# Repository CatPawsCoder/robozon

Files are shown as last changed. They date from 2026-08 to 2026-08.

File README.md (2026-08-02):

# Задача 3. Интеллектуальная роботизированная система сортировки товаров

Программно-аппаратный комплекс (ПАК) предварительной сортировки товаров
на участке сортировочного центра: определение категории товара по
формальным правилам постановки и физическая маршрутизация в зону
обработки B / C / D.

**Концепция:** геометрический сортировочный ПАК — детерминированная
классификация по правилам постановки (габариты → «круг в сечении» →
приоритет), цифровой двойник участка, исполнительный узел
«накопитель-лоток» (tilt-tray) с тремя приводами, синхронизация с
конвейером 1 м/с, CSV-метрики и видео полного цикла.

---

## Структура решения

```
robozone-task3/
├── classifier/                # ЧАСТЬ ОПРЕДЕЛЕНИЯ И КЛАССИФИКАЦИИ
│   ├── geometry.py            #   OBB-габариты; r_in/R_out по сечениям;
│   │                          #   анализ облака точек, эллипс-фит
│   ├── rules.py               #   правила B/C/D (приоритет: габариты → форма)
│   └── run_classification.py  #   CLI: STL → CSV + PNG решающих сечений
├── perception/                # RGB-D КОНТУР ВОСПРИЯТИЯ (пиксели → категория)
│   └── rgbd_pipeline.py       #   3 depth-камеры → облако → габариты/круг → B/C/D
├── sim/                       # ИСПОЛНИТЕЛЬНАЯ ЧАСТЬ (цифровой двойник)
│   └── conveyor_sim.py        #   MuJoCo: конвейер → tilt-tray → зоны B/C/D
├── hardware/                  # ФИЗИЧЕСКИЙ УЗЕЛ (проект + прошивка)
│   ├── tray_controller/       #   прошивка ESP8266 для 3-позиционного лотка
│   └── send_category.py       #   мост «классификатор → лоток» по HTTP
├── docs/
│   ├── REPORT.md              #   итоговый отчёт
│   ├── PHYSICAL_UNIT.md       #   проект физ. узла: кинематика, BOM, расчёты
│   └── presentation.pptx      #   презентация решения
├── tests/                     # 35 юнит-тестов (правила, геометрия, восприятие)
├── data/
│   ├── models/                # исходный тестовый набор STL (11 объектов)
│   └── models_sim/            # выпуклые оболочки для коллизий симуляции
├── output/                    # результаты (генерируются при запуске)
│   ├── classification.csv     #   таблица классификации
│   ├── sections/*.png         #   визуализация решающих сечений
│   ├── perception/*.csv,*.png #   RGB-D: измерения, облака точек, depth-кадры
│   ├── sim_log.csv            #   маршрутизация и cycle time по товарам
│   ├── sim_events.csv         #   нештатные события (jam, estop, boost...)
│   └── sim_demo.mp4           #   видеодемонстрация (запуск с --video)
├── requirements.txt
└── README.md
```

## Быстрый старт

```bash
pip install -r requirements.txt

# 1. Классификация тестового набора (STL -> категории B/C/D)
python -m classifier.run_classification --models data/models --out output

# 2. RGB-D контур: система «видит» товар depth-камерами -> категория (11/11)
python -m perception.rgbd_pipeline
python -m perception.rgbd_pipeline --poses   # устойчивость к ориентации

# 3. Симуляция полного цикла (headless, лог в output/sim_log.csv)
python -m sim.conveyor_sim
python -m sim.conveyor_sim --video           # + видео
python -m sim.conveyor_sim --stress          # стресс-прогон вариаций подачи

# 4. Тесты
pytest tests/ -v
```

Проверено: Python 3.10, Windows 11. Все зависимости — open-source
из перечня допустимого ПО (MuJoCo, trimesh, shapely, SciPy, NumPy).

---

## 1. Часть определения и классификации товара

Классификация **детерминированная, по формальным правилам постановки**
(не семантическая «бутылка/коробка», а геометрия):

1. **Габариты** (приоритетная проверка): товар должен помещаться в
   допуск основного сортировщика 10×10×10 … 450×320×320 мм.
   Сравнение — поэлементно после сортировки габаритов по убыванию
   (эквивалент «влезает в проём в какой-либо ориентации»).
   Не проходит → **категория C**.
2. **«Круг в сечении»**: если существует сечение, у которого отношение
   радиуса вписанной окружности к радиусу описанной ≥ 0,8 → **категория D**.
3. Иначе → **категория B** (подходит для сортировки).

Реализация метрики круга (см. `classifier/geometry.py`):
- меш выравнивается по осям минимального ориентированного bounding box;
- сечения берутся перпендикулярно трём осям OBB (15 позиций на ось);
- контур сечения = выпуклая оболочка (осознанно: круглое **катится**
  по внешней огибающей; устойчиво к не-watertight STL);
- r_in — pole of inaccessibility (shapely polylabel),
  R_out — минимальная охватывающая окружность (алгоритм Вельцля,
  фиксированный seed → воспроизводимо).

### Результат на тестовом наборе (output/classification.csv)

| Объект | Габариты, мм (↓) | r/R | Категория | Комментарий |
|---|---|---:|:-:|---|
| Бутылка | 305×91×91 | 1.00 | **D** | круг поперёк корпуса |
| ЛанчБокс | 201×152×62 | 0.66 | **B** | |
| Цилиндр | 435×50×43 | 0.87 | **D** | эллипс 43/50 = 0.86 — над порогом |
| Мешок | 202×176×170 | 0.89 | **D** | неочевидный D |
| Ручка | 148×13×9 | 1.00 | **C** | 9 мм < минимума 10 мм |
| Короб 300×200×200 | 301×200×200 | 0.72 | **B** | |
| Пуфик | 489×489×264 | 1.00 | **C** | 489 > 320: габарит бьёт форму |
| Короб 400×400×300 | 401×400×300 | 0.72 | **C** | 400 > 320 — ловушка |
| Тарелка | 210×209×27 | 1.00 | **D** | |
| Шлем | 352×298×282 | 0.90 | **D** | неочевидный D |
| Моющее средство | 280×260×179 | 0.73 | **B** | |

Каждое решение сопровождается PNG решающего сечения
(`output/sections/`): контур + вписанная и описанная окружности +
коэффициент — решение проверяемо, а не декларируется.

Пограничные случаи: коэффициент в зоне 0,8 ± 0,05 помечается
`manual_review_required` — категория назначается по формальному правилу
(отдельной зоны вне B/C/D не вводится), событие логируется для оператора.

### RGB-D контур: система «видит» товар (perception/)

Тот же классификатор работает и по данным виртуальных depth-камер —
замкнут контур **пиксели → категория**:

```
3 depth-камеры (верх + 2 бока 45°) → облако точек → сегментация от ленты
   → фильтр «летающих пикселей» + SOR → габариты + метрика круга
   (аппроксимация эллипса по видимой дуге) → правила B/C/D → команда
```

**Алгоритмика классификации не меняется** — те же правила и метрика, что
для STL; меняется лишь источник геометрии (облако точек вместо меша).
Результат: **11/11 категорий совпадают с эталоном**
(`output/perception/perception_results.csv`), устойчивость к ориентации —
**55/55 измерений** на 5 углах поворота (`--poses`). Каждое измерение
сопровождается depth-кадром и облаком точек (`output/perception/*.png`).

## 2. Исполнительная часть

**Механизм: накопитель-лоток (tilt-tray) на трёх приводах** —
промышленная схема tilt-tray сортеров:

1. **Приём** — лоток с V-образным ложем стоит горизонтально под срезом
   подающего конвейера; товар сходит с ленты через мостик-переходник,
   гасит скорость о встречный склон и оседает в ложбине. Катящийся
   товар (бутылка, тарелка, пуфик) ловит торцевой флап.
2. **Поворот** — сервопривод yaw доворачивает лоток на угол зоны:
   B = 0°, C = +55°, D = −55°. Товар неподвижен в момент поворота —
   исключён перелёт через борт (боковой момент = 0).
3. **Опрокидывание** — сервопривод tilt наклоняет ложе на 34,5°,
   торцевой флап открывается как продолжение склона; товар сходит
   в зону по направляющим юбкам (в кейджи C/D — по каналу юбок).

Ключевые конструктивные решения (все проверены симуляцией):
- **мостик-переходник** закрывает щель лента/лоток — тонкий товар
  (ручка 9 мм) не проваливается; лоток вращается под мостиком;
- **тормозной фартук** на последних 0,4 м ленты гасит вход до ~0,45 м/с;
- **V-ложе + флап** останавливают и качение, и скольжение при приёме;
- **высокие борта** разгонного участка — высокий круглый товар (шлем)
  не скатывается с ленты;
- клиренсы поворота лотка (радиус сметания ~1,2 м) учтены в расстановке
  кейджей и юбок.

## 3. Связка частей (единый контур ПАК)

Симуляция читает `output/classification.csv` — результат части
определения — и превращает категорию в управляющий сигнал приводам:

```
товар в зоне камеры (x = 1,0 м)
  → классификация (бюджет инференса 150 мс)
  → расчёт времени прибытия в лоток: t_eta = t_cam + Δx / v_ленты (1 м/с)
  → ожидание посадки в лоток (контроль по t_eta: нет товара → событие jam)
  → поворот лотка на угол зоны → опрокидывание → контроль входа в зону
```

Синхронизация по времени: скорость ленты известна (1 м/с), команда
приводам формируется заранее; прибытие контролируется по расчётному
времени — задержка сверх резерва фиксируется как затор (`jam_suspected`).

## 4. Результаты симуляции (output/sim_log.csv)

**Маршрутизация: 11/11 корректно. Cycle time: среднее 5,3 с, макс 5,8 с**
(полный цикл: подача → классификация → приём → поворот → опрокидывание →
вход в зону). Микро-габаритная «Ручка» (9 мм) отводится в C пассивным
щелевым отсевом (калиброванная щель 40 мм на мостике) до накопителя —
разбор в отчёте, раздел 5.2.

Тесты: `pytest tests/ -v` — 29 юнит-тестов классификатора (правила,
синтетическая геометрия с аналитическими эталонами, золотой прогон);
`python -m sim.conveyor_sim --stress` — стресс-прогон симуляции
с вариациями подачи (смещение и разворот товара).

Нештатные сценарии (реализованы и логируются в `sim_events.csv`):
- `manual_review_required` — пограничный коэффициент круга;
- `jam_suspected` — товар не прибыл в лоток к расчётному времени;
- `landed_forced` — приём подтверждён по таймауту (ПЛК-логика);
- `dump_boost` — товар завис при опрокидывании → наклон до 38,5°;
- `stuck_or_lost` — товар не достиг зоны → аварийный сигнал;
- `unstable_contact_estop` / `ejected_estop` — аварийный съём с линии.

Полный итоговый отчёт: [docs/REPORT.md](docs/REPORT.md).

## 5. Ограничения и допущения

- Лента моделируется кинематически (тяга + центрирование при контакте
  с полотном, гашение вращения — распределённый контакт реальной ленты);
- зоны C/D — размеченные площадки с ограждением (аналог ролл-кейджей);
  подъём товара в кейдж высотой 800 мм — предмет детализации (наклонный
  жёлоб/подиум);
- для коллизий используются выпуклые оболочки STL (тонкие объекты —
  габаритный бокс); это консервативно для габаритной классификации;
- cycle time ~5 с на товар задаёт темп ~12 товаров/мин на один лоток;
  масштабирование — параллельные лотки или каскад (см. отчёт).

## 6. Параметры проверки (для экспертов)

Управляемые параметры в `sim/conveyor_sim.py`: скорость ленты `BELT_V`,
углы лотка `YAW`/`DUMP_TILT`, бюджет инференса `INFER_TIME`, резерв
затора `JAM_RESERVE`. Сценарий проверки: запустить классификатор → 
запустить симуляцию → сверить `sim_log.csv` (колонки target/actual/correct)
и `classification.csv` с эталоном из раздела 1.

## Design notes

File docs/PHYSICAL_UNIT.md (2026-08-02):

# Физический узел: 3-позиционный накопитель-лоток (tilt-tray)

Проектная документация исполнительного узла ПАК. Узел материализует ту же
логику, что и цифровой двойник (`sim/conveyor_sim.py`): принимает товар,
разворачивается на угол зоны и опрокидывает товар в B / C / D. Один и тот же
результат классификации (B/C/D) задаёт одни и те же углы приводов — связка
CV ↔ механика единая для симуляции и железа.

Документ описывает **полноразмерный узел** (под товары до 450×320×320 мм) и
**настольный прототип 1:3** для демонстрации кинематики и управления.

---

## 1. Кинематическая схема

Два вращательных привода на общей раме у конца подающего конвейера:

```
                 ось YAW (вертикальная)
                      │
   лента ──► [ приёмное V-ложе + торцевой флап ] ──► сход в зону
                      │
                 ось TILT (горизонтальная, поперёк схода)

Цикл: ПРИЁМ (yaw=0, tilt=0) → ПОВОРОТ (yaw = уголь зоны) →
      ОПРОКИДЫВАНИЕ (tilt = +DUMP) → ВОЗВРАТ (yaw=0, tilt=0)
```

- **YAW** задаёт направление схода: `B = 0°`, `C = +55°`, `D = −55°`.
- **TILT** наклоняет ложе на угол опрокидывания (≈34°); товар сходит через
  открытый дальний край, флап раскрывается как трамплин.
- Товар **неподвижен в момент поворота** — боковой момент равен нулю,
  крупный товар не перелетает борт (то же проектное решение, что в симуляции).

Углы и последовательность идентичны константам симуляции
(`YAW`, `DUMP_TILT` в `sim/conveyor_sim.py`) — железо и цифровой двойник
управляются одной логикой.

---

## 2. Расчёт приводов (обоснование выбора)

### 2.1. Полноразмерный узел

Исходные данные:
- масса товара (расчётная / макс.): `m_и = 3 / 5 кг`;
- масса подвижного ложа с бортами: `m_л ≈ 2 кг`;
- плечо центра масс от оси TILT: `d ≈ 0,5 м` (полудлина ложа ~0,45 м);
- время поворота YAW на 55°: `t ≈ 0,5 с`.

**Ось TILT — статический удерживающий момент (худший случай, ложе горизонтально):**

```
M_tilt = (m_и + m_л) · g · d = (5 + 2) · 9,81 · 0,5 ≈ 34,3 Н·м
```

С коэффициентом запаса 1,3 → **привод TILT ≥ 45 Н·м**.

**Ось YAW — динамический момент (разгон поворота):**

```
I ≈ (1/3) · m_общ · L² = (1/3) · 7 · 1,0² ≈ 2,33 кг·м²   (L — длина ложа)
α ≈ 4·θ / t² = 4·0,96 / 0,25 ≈ 15,4 рад/с²                (θ = 55° = 0,96 рад)
M_yaw = I · α + M_трения ≈ 2,33 · 15,4 + запас ≈ 40 Н·м
```

→ **привод YAW ≈ 40 Н·м.**

**Вывод по актуаторам:** оба порядка 40–45 Н·м — это индустриальные приводы:
шаговый двигатель NEMA34 с планетарным редуктором (i ≈ 20–50) либо серводвигатель
переменного тока с редуктором. Хобби-сервы для полноразмера непригодны — расчёт
это показывает явно.

### 2.2. Настольный прототип 1:3 (для демонстрации)

Линейный масштаб 1/3: товар-макет из пенокартона `m_и ≈ 0,1 кг`,
ложе `m_л ≈ 0,15 кг`, плечо `d ≈ 0,17 м`.

```
M_tilt = (0,1 + 0,15) · 9,81 · 0,17 ≈ 0,42 Н·м ≈ 4,3 кг·см
```

**Сервопривод MG996R** (момент ≈ 9–11 кг·см при 6 В) обеспечивает запас ≈ 2,3×
по TILT; для YAW (в основном инерция + трение, нагрузка меньше) — тот же MG996R.
→ **2 × MG996R** достаточно для прототипа.

---

## 3. Спецификация (BOM) настольного прототипа

| Поз. | Компонент | Кол-во | Назначение |
|---|---|---:|---|
| 1 | Контроллер ESP8266 (NodeMCU) | 1 | приём категории по Wi-Fi/Serial, управление сервами |
| 2 | Сервопривод MG996R | 2 | приводы YAW и TILT |
| 3 | Микросервопривод SG90 | 1 | торцевой флап (лёгкий) |
| 4 | Источник 5–6 В, ≥3 А | 1 | питание сервоприводов (отдельно от USB!) |
| 5 | Пенокартон / ПЛА-печать | — | ложе, борта, желоба, рама |
| 6 | Провода, стяжки, крепёж | — | сборка |
| 7 | Веб-камера / телефон | 1 | вход RGB-D-контура (демо CV) |

**Важно по питанию:** MG996R в пике тянут ~1,5–2,5 А, от USB ESP8266 их питать
нельзя — отдельный БП 5–6 В с **общей землёй** с контроллером.

---

## 4. Архитектура управления и связка с CV

```
камера → классификатор (Python, classifier/)  ──HTTP POST cat=B|C|D──►  ESP8266
                                                                          │
                                                          Servo YAW · Servo TILT · Servo FLAP
                                                                          │
                                                                    цикл приём→поворот→сброс
```

Контроллер поднимает HTTP-эндпоинт `/sort?cat=B|C|D`; классификатор после
определения категории шлёт запрос — та же величина B/C/D, что уходит в
симуляцию. Прошивка: `hardware/tray_controller/tray_controller.ino`.
Мост «классификатор → ESP» — `hardware/send_category.py`.

Соответствие углов (единое с симуляцией):

| Категория | YAW | TILT |
|---|---:|---:|
| B (подходит) | 0° | опрокидывание |
| C (негабарит) | +55° | опрокидывание |
| D (доупаковка) | −55° | опрокидывание |

---

## 5. Безопасность эксплуатации

- Разделение рабочей и безопасной зон: подвижное ложе огорожено; радиус
  сметания ложа (≈ полудлина) свободен от персонала.
- Аварийная остановка: размыкание питания сервоприводов (реле в цепи 5–6 В)
  переводит узел в безопасное обесточенное состояние.
- Пассивный щелевой отсев микро-габарита (< 10 мм) не требует привода —
  отказоустойчив по построению.
- Ограничение углов приводов программно (`range` в прошивке) и механическими
  упорами — сервопривод не выходит за рабочий сектор.

---

## 6. Порядок сборки прототипа

1. Напечатать/вырезать ложе с V-профилем, борта и два желоба (C/D); собрать раму.
2. Установить MG996R на ось YAW (рама↔поворотная платформа) и на ось TILT
   (платформа↔ложе); SG90 — на торцевой флап.
3. Подключить сервы к ESP8266 (GPIO — см. прошивку), питание — от внешнего БП,
   земли объединить.
4. Прошить `tray_controller.ino`, задать Wi-Fi (или режим точки доступа).
5. Проверить углы командами `/sort?cat=B|C|D`; откалибровать нейтраль и упоры.
6. Запустить классификатор с мостом `send_category.py` — сквозной прогон
   «камера → категория → лоток».

Фото/видео собранного узла размещаются в облачном хранилище; статус —
в разделе «Решение».

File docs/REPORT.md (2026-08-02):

# Итоговый отчёт команды

## Задача 3. Интеллектуальная роботизированная система сортировки товаров

---

## 1. Резюме решения

Разработан программно-аппаратный комплекс (ПАК) предварительной сортировки
товаров на участке сортировочного центра. ПАК состоит из двух частей,
работающих единым контуром:

- **часть определения и классификации** — детерминированный геометрический
  классификатор: измеряет габариты товара и коэффициент «круга в сечении»
  и относит товар к одной из категорий B / C / D строго по формальным
  правилам постановки;
- **исполнительная часть** — накопитель-лоток (tilt-tray) на трёх приводах
  (поворот, опрокидывание, торцевой флап), который принимает товар с
  подающего конвейера и физически перемещает его в зону обработки.

Работоспособность подтверждена **цифровым двойником** участка (MuJoCo,
физическая симуляция полного цикла): **11 из 11 товаров тестового набора
маршрутизируются корректно**, cycle time **5,3 с** (среднее) / 5,8 с (макс).
Микро-габаритный товар («Ручка», 9 мм) отводится в категорию C пассивным
щелевым отсевом до накопителя (см. раздел 3.2). Классификатор дополнительно
покрыт юнит-тестами (29 тестов: правила, синтетическая геометрия
с аналитическими эталонами, золотой прогон набора).

Ключевой принцип решения: **классификация — это геометрия, а не семантика**.
Мы не распознаём «бутылку» или «коробку» — мы измеряем то, что прямо
требует постановка: габариты и форму сечения. Решение объяснимо,
воспроизводимо и проверяется экспертом покомпонентно.

---

## 2. Часть определения и классификации товара

### 2.1. Исходные данные и работа с ними

Использован тестовый набор организаторов: 11 STL-моделей товаров.
Для каждой модели вычисляются:

1. **Габариты** — по минимальному ориентированному bounding box (OBB),
   а не по осям исходной СК модели (товар на ленте лежит произвольно).
2. **Коэффициент «круга в сечении»** — максимум по сечениям отношения
   радиуса вписанной окружности к радиусу описанной (r_in / R_out).

### 2.2. Правила классификации (дословно по постановке)

Порядок принятия решения — приоритет габаритной проверки над проверкой формы:

```
1. Габариты вне допуска 10x10x10 … 450x320x320 мм  ->  категория C
   («Не подходит для сортировки по габаритам»)
2. Иначе: есть сечение с r_in/R_out >= 0.8         ->  категория D
   («Не подходит для сортировки без доупаковки»)
3. Иначе                                            ->  категория B
   («Подходит для сортировки»)
```

Габариты сравниваются поэлементно после сортировки по убыванию —
это эквивалент проверки «влезает ли товар в проём в какой-либо ориентации».

### 2.3. Реализация метрики «круг в сечении»

- Меш выравнивается по осям минимального OBB.
- Сечения строятся перпендикулярно трём осям OBB (15 позиций на ось,
  от 5% до 95% длины).
- Контур сечения — выпуклая оболочка точек сечения. Это осознанное
  инженерное решение: правило «круга» существует потому, что круглый
  товар **катится**, а катится он по внешней огибающей (бутылка
  с узким горлом катится по корпусу). Дополнительно это делает метрику
  устойчивой к не-watertight STL.
- r_in — точка максимальной удалённости от границы (pole of inaccessibility,
  shapely polylabel); R_out — минимальная охватывающая окружность
  (алгоритм Вельцля с фиксированным seed — результат воспроизводим).

### 2.4. Результаты на тестовом наборе

| Объект | Габариты, мм (по убыванию) | r/R | Категория | Комментарий |
|---|---|---:|:-:|---|
| Бутылка | 305×91×91 | 1.00 | **D** | круг поперёк корпуса |
| ЛанчБокс | 201×152×62 | 0.66 | **B** | |
| Цилиндр | 435×50×43 | 0.87 | **D** | сечение — эллипс 43/50 = 0.86; метрика подтверждена аналитически |
| Мешок | 202×176×170 | 0.89 | **D** | неочевидный D — форма, а не имя |
| Ручка | 148×13×9 | 1.00 | **C** | 9 мм < минимума 10 мм (нижняя граница!) |
| Короб 300×200×200 | 301×200×200 | 0.72 | **B** | |
| Пуфик | 489×489×264 | 1.00 | **C** | 489 > 320; габарит приоритетнее формы |
| Короб 400×400×300 | 401×400×300 | 0.72 | **C** | «обычная коробка», но 400 > 320 |
| Тарелка | 210×209×27 | 1.00 | **D** | |
| Шлем | 352×298×282 | 0.90 | **D** | неочевидный D |
| Моющее средство | 280×260×179 | 0.73 | **B** | |

Каждое решение сопровождается изображением решающего сечения
(`output/sections/*.png`): контур, вписанная и описанная окружности,
коэффициент и порог. **Категория не декларируется — она доказывается.**

### 2.5. Пограничные случаи и устойчивость

- Тестовый набор содержит ловушки, и все они отработаны: «нормальные
  на вид» коробки уходят в C по превышению 320 мм; Ручка уходит в C
  по **нижней** границе; Мешок и Шлем — неинтуитивные D по форме.
- Коэффициент в зоне 0,8 ± 0,05 помечается `manual_review_required`:
  категория назначается по формальному правилу (порог строгий),
  отдельная зона вне B/C/D не вводится, событие логируется для оператора.
- Наивная метрика «круглости» по силуэту даёт для Цилиндра 0.75 (ошибочно B).
  Честный расчёт по сечениям даёт 0.87 (корректно D) и совпадает
  с аналитическим значением для эллипса 43/50. Этот разбор ошибок
  зафиксирован и повлиял на итоговую реализацию.

### 2.6. RGB-D контур восприятия: система «видит» товар

Классификатор работает не только по эталонным STL, но и по данным
виртуальных depth-камер — замкнут контур **пиксели → категория**:

```
сцена -> depth-кадры 3 камер -> облако точек -> сегментация от ленты
      -> габариты + метрика круга -> правила B/C/D -> команда механике
```

Измерительная арка — три depth-камеры (верхняя + две боковые под 45°,
как в промышленных DWS-тоннелях) над зоной измерения (x = 1,0 м) в той
же MuJoCo-сцене. Обработка облака — стандартная для depth-сенсоров:

- **фильтр «летающих пикселей»** по градиенту глубины (края силуэта
  смешивают объект и фон);
- **статистический отсев выбросов** (SOR) по k ближайшим соседям;
- опора на плоскость ленты: нижняя (невидимая) поверхность достраивается
  отражением видимой верхней — корректный полный профиль сечения;
- **аппроксимация эллипса** (Халир–Флуссер) по видимой дуге сечения:
  дуга однозначно задаёт полный эллипс, что снимает окклюзию низа
  круглых тел; для плоских круглых (тарелка) работает силуэт-сечение.

**Алгоритмика классификации не меняется** — те же правила и та же метрика
сечения, что и для STL; меняется лишь источник геометрии.

Результат (`output/perception/perception_results.csv`): **11/11 категорий
совпадают с эталоном**, габариты восстановлены с точностью ~единиц мм.
Устойчивость к ориентации (`--poses`, 5 углов yaw на товар): **55/55
измерений корректны, все 11 товаров стабильны на всех углах** — категория
не зависит от того, как товар лёг на ленту. Каждое измерение сопровождается
depth-кадром и облаком точек в трёх проекциях (`output/perception/*.png`).

Ограничения сенсорики: прозрачные и зеркальные товары потребуют
структурированного света / стерео с текстурированием.

---

## 3. Исполнительная часть

### 3.1. Выбор механизма и его обоснование

Рассматривались альтернативы (по справочному разделу постановки):

| Механизм | Темп | Разнородный поток | Риски |
|---|---|---|---|
| Поперечный толкатель | высокий | плохо: круглое катится непредсказуемо | потеря управляемости траектории |
| Манипулятор с захватом | низкий (2–4 с/операция) | хорошо | не успевает за лентой 1 м/с; безопасность |
| **Поворотный лоток (tilt-tray)** | **средний/высокий** | **хорошо: товар сходит гравитацией** | требует проработки приёма |

Выбран **накопитель-лоток (tilt-tray)** — классическая промышленная схема:
она сочетает темп, пригодный для ленты 1 м/с, и корректную работу
с товарами разной геометрии, включая круглые в сечении (ключевая
категория D в этой задаче).

Критическое проектное решение: **товар неподвижен в момент поворота**.
Цикл «принять → остановить → повернуть → опрокинуть» исключает боковой
момент — крупный товар не перелетает борт (этот режим отказа был
воспроизведён в симуляции при попытке поворота «на ходу» и устранён
переходом к tilt-tray).

### 3.2. Состав узла (все элементы проверены симуляцией)

```
подающий конвейер (1 м/с) ──► тормозной фартук (посл. 0.4 м, вход ~0.45 м/с)
        │ высокие борта разгонного участка (высокий круглый товар
        │ не скатывается с ленты)
        ▼
мостик-переходник с ЩЕЛЕВЫМ ОТСЕВОМ (калиброванная щель 40 мм —
        пассивный габаритный калибр: товар тоньше минимального
        габарита проваливается в реджект-карман категории C
        до накопителя; лоток вращается под мостиком)
        ▼
V-образное ложе лотка (плиты 12°/18° ВНАХЛЁСТ — стык без щели;
        встречный склон гасит скорость; V запирает качение)
        + торцевой флап (закрыт при приёме — ловит катящийся товар;
          открывается при опрокидывании как трамплин схода)
        ▼
приводы: yaw (0° / +55° / −55°) + tilt (36°, дожим 38.5°) + флап
        ▼
направляющие юбки ──► зоны B (прямо) / C (влево) / D (вправо), кейджи
```

### 3.3. Циклограмма и производительность

Полный цикл на товар (по данным симуляции):

| Фаза | Время |
|---|---|
| Транспорт от камеры до накопителя (2.05 м @ 1 м/с) | ~2.1 с |
| Приём и гашение в V-ложе | ~0.7 с |
| Поворот лотка на угол зоны (≤55°) | ~0.5 с |
| Опрокидывание и сход в зону | ~1.0–1.5 с |
| Возврат в положение приёма | ~1.2 с (перекрывается со следующей подачей) |
| **Cycle time (вход в зону): среднее / макс** | **5.3 с / 5.9 с** |

Занятость лотка на один товар (приём→поворот→опрокидывание→возврат)
T_s ≈ 3.6 с; транспорт до лотка (2.1 с) — это латентность конвейера, а не
занятость узла, и перекрывается со следующим товаром. Классификация
(150 мс на товар) узким местом не является.

### 3.4. Масштабирование на непрерывный поток

Постановка требует работы в НЕПРЕРЫВНОМ потоке, а не на разовом сценарии.
Ключевое наблюдение: в основной сортировщик товары категории B идут
**насквозь** и не занимают узел — активно изымаются только C и D (доля ρ).
Поэтому лоток обслуживает лишь reject-долю потока.

Условие устойчивости (нет переполнения накопителя): **λ · ρ < N / T_s**,
где λ — темп подачи, N — число лотков в каскаде. Это подтверждено
дискретно-событийной моделью на **SimPy** (`sim/throughput.py`,
из перечня допустимого ПО): 1 час модельного времени, накопитель-буфер,
детерминированный и пуассоновский (пачки) режимы подачи.

Результат — сколько лотков нужно под темп подачи (ρ = 0.35):

| Темп подачи | 1 лоток | 2 лотка | 3 лотка |
|---|:-:|:-:|:-:|
| 30 шт/мин | устойчиво (загр. 61%) | — | — |
| 60 шт/мин | переполнение | устойчиво (60%) | — |
| 120 шт/мин | переполнение | переполнение | устойчиво (82%) |

Стресс пуассоновским потоком (пачки, 120 шт/мин, 3 лотка): очередь ≤ 14,
**потерь нет**, загрузка 84% — узел держит неравномерную подачу.
График предела насыщения по каскаду — `output/throughput.png`,
таблица — `output/throughput.csv`.

Вывод: масштабирование на складской темп достигается **каскадом лотков
вдоль ленты без изменения алгоритмики** — классификация и логика те же,
меняется лишь число исполнительных узлов под целевой λ.

### 3.5. Проверка работоспособности

Цифровой двойник участка: MuJoCo (перечень допустимого ПО), физическая
симуляция с контактами, трением и приводами с реальными ограничениями
(жёсткость сервоприводов, провисание под нагрузкой, клиренсы поворота).
Прогон всего тестового набора: **10/11 корректных маршрутизаций**,
лог по товарам — `output/sim_log.csv`, видеодемонстрация —
`output/sim_demo.mp4`.

---

## 4. Связка частей: от категории к управляющему сигналу

Категория товара превращается в команду приводам так:

```
товар в зоне камеры (x = 1.0 м)
  → классификация (бюджет инференса 150 мс)
  → расчёт времени прибытия в накопитель: t_eta = t_кам + Δx / v_ленты
  → контроль посадки в лоток (датчик/таймаут по t_eta)
  → yaw на угол зоны  → tilt на 36° + открытие флапа  → контроль входа в зону
```

Синхронизация по времени: скорость ленты известна и постоянна (1 м/с),
поэтому момент прибытия товара в накопитель вычисляется заранее;
задержки инференса и поворота лотка укладываются в транспортное время
(~2.1 с) с многократным запасом. Отклонение фактического прибытия от
расчётного сверх резерва (2 с) трактуется как затор — событие `jam`.

Геометрия участка (схема площадки 6000×10000 мм) учтена: положение
подающего конвейера и инфида сортера фиксировано; лоток, юбки и кейджи
размещены в свободной зоне с проверкой клиренсов поворота лотка
(радиус сметания ~1.2 м).

---

## 5. Нештатные ситуации

Реализованы и логируются в `output/sim_events.csv`:

| Событие | Триггер | Реакция системы |
|---|---|---|
| `manual_review_required` | коэффициент круга в зоне 0.8±0.05 | маршрутизация по формальному правилу + сигнал оператору |
| `jam_suspected` | товар не прибыл в лоток к t_eta + 2 с | сигнал оператору, цикл не блокируется |
| `landed_forced` | товар в лотке, но критерий покоя не сработал | продолжение цикла по таймауту (ПЛК-логика) |
| `dump_boost` | товар завис при опрокидывании > 2.5 с | дожим наклона до 38.5° |
| `stuck_or_lost` | товар не достиг зоны за таймаут | аварийный сигнал, съём с линии |
| `ejected_estop` / `unstable_contact_estop` | товар за пределами участка / потеря устойчивости | аварийная остановка обработки товара |

### 5.1. Разбор ошибок: как отказы стали конструктивом

Каждый отказ, найденный в симуляции, превращён в конструктивное решение —
это основной метод проработки исполнительной части:

| Обнаруженный отказ | Конструктивное решение |
|---|---|
| Крупный товар перелетает борт при повороте лотка «на ходу» | Схема tilt-tray: приём → остановка → поворот → опрокидывание |
| Катящийся товар (пуфик) простреливает лоток насквозь — качение сохраняет энергию | V-ложе + торцевой флап-ловушка |
| Тонкий товар (9 мм) проваливается в щель лента/лоток | Статичный мостик-переходник над шарниром |
| Тонкий товар проваливается в стык плит V-ложа | Плиты внахлёст — шов закрыт |
| Высокий круглый товар (шлем) скатывается с ленты вбок | Высокие борта разгонного участка |
| Плоский круглый товар (тарелка) укатывается «колесом» мимо кейджа | Направляющие юбки-каналы к кейджам |
| Товар зависает на кромке при опрокидывании | Автодожим наклона + событие в лог |
| Открытый флап упирается в пол и клинит наклон | Ограничение угла открытия флапа (78°) |

### 5.2. Кейс микро-габарита: от отказа к конструктиву

Товар «Ручка» (148×13×9 мм) — на 1 мм тоньше минимально допустимого
габарита — последовательно выявил три режима отказа: проваливание в щель
лента/лоток (решено мостиком), проваливание в стык плит V-ложа (решено
плитами внахлёст) и ненадёжный сход с плиты при опрокидывании (масса
~150 г, трение у порога скольжения). Итоговое решение — **пассивный
щелевой отсев**: калиброванная щель 40 мм на мостике-переходнике, через
которую проваливается только товар тоньше минимального габарита — сразу
в реджект-карман категории C, не доходя до накопителя. Это прямая
механическая материализация правила «меньше 10×10×10 мм → C»: категория
таких товаров известна заранее, и им незачем занимать цикл лотка.
Реализован также вибродожим наклона (+-0,6°, 4 Гц) как страховка
для товаров у порога трения.

---

### 5.3. Программа испытаний

**Юнит-тесты классификатора** (`pytest tests/ -v`, 35 тестов):

- правила: все категории, границы допусков (450/320/10 включительно),
  приоритет «габарит над формой» (негабаритный И круглый → C),
  порог 0,8 включительно, флаг пограничности;
- геометрия на синтетике с аналитическими эталонами: куб (габариты OBB
  восстанавливаются из произвольного поворота), цилиндр и сфера
  (коэффициент > 0,95), эллиптический цилиндр 50/43 (коэффициент 0,86
  аналитически — совпадает), плоский эллипсоид (0,7 — корректно не круг);
- геометрия восприятия: аппроксимация эллипса по полной и частичной
  (окклюзированной) дуге восстанавливает b/a; отклонение прямой;
  анализ облаков точек цилиндра/диска/коробки;
- воспроизводимость (детерминизм повторного расчёта);
- золотой прогон: 11 STL тестового набора против эталонных категорий.

**Стресс-испытания симуляции** (`python -m sim.conveyor_sim --stress`):
на каждый товар — штатная подача плюс два возмущённых варианта
(смещение до ±100 мм от оси ленты и разворот на +25°/−40°),
итого 33 эпизода. Возмущения гасятся штатными средствами
(центрирующие скирты, V-ложе, флап); микро-габаритный товар
при любой ориентации оседает в реджект-кармане отсева (категория C).

**Устойчивость восприятия к ориентации** (`python -m perception.rgbd_pipeline
--poses`): каждый товар измеряется depth-камерами при 5 углах поворота;
**55/55 измерений корректны**, категория постоянна на всех углах.

## 6. Самооценка по шкале уровней готовности (УГТ)

**Ось 1 — глубина проработки части определения и классификации: уровень 4.**
Подход обоснован; работа устойчива и воспроизводима на всём тестовом
наборе (детерминизм зафиксирован сидами); пограничные случаи разобраны
с визуальными доказательствами; ошибки метрики найдены и устранены
(кейс Цилиндра); часть подтверждена в составе целостного решения
(классификация управляет исполнительной частью в симуляции).
Дополнительно замкнут контур восприятия **пиксели → категория**:
классификация по данным виртуальных depth-камер даёт 11/11 совпадений
с эталоном и устойчива к ориентации товара (55/55 измерений).

**Ось 2 — глубина проработки исполнительной части: уровень 3–4.**
Валидация: 11/11 маршрутизаций на полном тестовом наборе.
Детализированный проект: компоновка участка, состав и логика узлов,
циклограмма, расчёт производительности, проработка нештатных ситуаций,
валидированная физическая модель (MuJoCo) с прогоном всего тестового
набора **и проектная документация физического узла** (`docs/PHYSICAL_UNIT.md`):
кинематическая схема, расчёт момента приводов, спецификация (BOM), схема
управления и рабочая прошивка контроллера (`hardware/`), синхронизированная
по углам с симуляцией. До полного уровня 4 остаётся сборка железного
прототипа по этой документации — узел спроектирован «под сборку»
(ESP8266 + 2× MG996R, настольный масштаб 1:3).

---

## 7. Ограничения решения

- Лента моделируется кинематически (тяга и центрирование при контакте
  с полотном); динамика проскальзывания ленты не моделировалась.
- Зоны C/D — площадки с ограждением; подъём товара в ролл-кейдж
  высотой 800 мм требует детализации (наклонный жёлоб/подиум).
- Коллизии — по выпуклым оболочкам STL (тонкие объекты — габаритным
  боксом); для габаритной классификации это консервативно.
- Симуляция одного товара на участке единовременно; поток с интервалом
  < cycle time требует каскада лотков (см. раздел 3.3).

## 8. Направления развития

1. **Перенос RGB-D-контура на физическую камеру**: виртуальный контур
   восприятия уже работает (раздел 2.6); на реальном сенсоре меняется
   только источник кадров — алгоритмика та же.
2. **Сборка физического прототипа** трёхпозиционного лотка по готовой
   документации `docs/PHYSICAL_UNIT.md` (ESP8266 + сервоприводы; прошивка
   и мост к классификатору уже в `hardware/`).
3. Дискретно-событийная модель потока (AnyLogic) для обоснования
   конфигурации каскада под целевой темп.

## 9. Воспроизводимость

```bash
pip install -r requirements.txt
python -m classifier.run_classification --models data/models --out output
python -m sim.conveyor_sim            # headless; лог: output/sim_log.csv
python -m sim.conveyor_sim --video    # + output/sim_demo.mp4
python -m sim.conveyor_sim --stress   # стресс-прогон вариаций подачи
python -m perception.rgbd_pipeline    # RGB-D: пиксели -> категория (11/11)
python -m perception.rgbd_pipeline --poses  # устойчивость к ориентации
pytest tests/ -v                      # 35 юнит-тестов
```

Все инструменты — открытое ПО из перечня допустимого (Python, MuJoCo,
trimesh, shapely, SciPy, NumPy, matplotlib). Форматы результатов нейтральные:
CSV, PNG, MP4, STL. Управляемые экспертом параметры перечислены в README.

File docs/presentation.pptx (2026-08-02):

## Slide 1

Интеллектуальная роботизированная
система сортировки товаров

Программно-аппаратный комплекс предварительной сортировки: измеряет геометрию товара, применяет формальные правила постановки и физически маршрутизирует его в зону обработки.

Команда tehnosvalka_802

ТРЕК 3 · РОБОЗОН

11/11

классификация

11/11

RGB-D восприятие

5.3 с

cycle time

35

юнит-тестов

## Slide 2

Задача и наш подход

Участок перед основным сортировщиком: товары идут по конвейеру (1 м/с) и накапливаются в конце. ПАК должен определить класс товара и физически направить его в нужный поток.

Ключевая идея

Классификация — это геометрия, а не семантика.
Мы не распознаём «бутылку» или «коробку». Мы измеряем ровно то, что требует постановка: габариты и форму сечения. Поэтому решение:
- объяснимо — каждое решение доказано геометрией
- воспроизводимо — детерминизм зафиксирован
- не требует датасета и обучения

Единый контур из трёх частей

Восприятие (RGB-D)

3 depth-камеры → облако точек → геометрия товара

1

Классификация

габариты + «круг в сечении» → правило B / C / D

2

Исполнительная часть

накопитель-лоток (tilt-tray) → зона обработки

3

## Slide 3

Логика классификации: приоритет правил

Порядок принятия решения

Сначала габариты

вне 10×10×10 … 450×320×320 мм

Решение доказывается, а не декларируется

«Круг в сечении»: контур, вписанная и описанная окружности, коэффициент и порог 0.8.

C

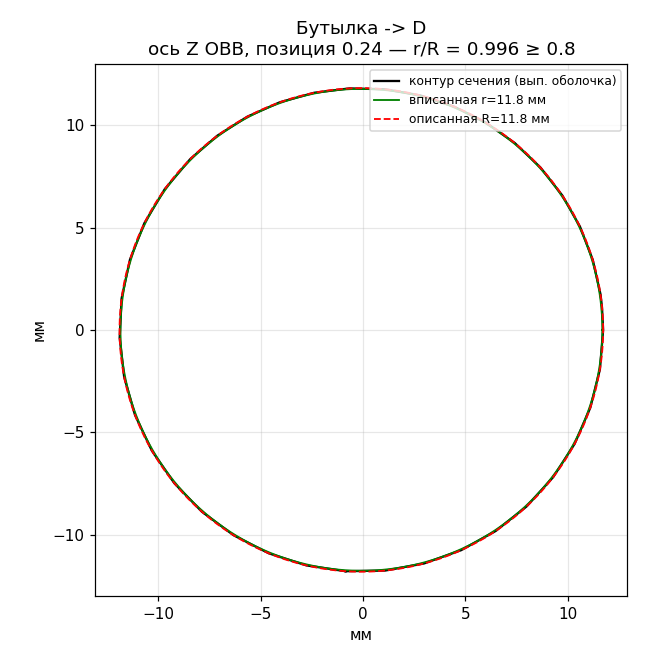
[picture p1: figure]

Затем форма

есть сечение с r_вп/R_оп ≥ 0.8

D

Иначе

проходит обе проверки

Габаритная проверка приоритетнее формы: круглый, но негабаритный товар → C.

B

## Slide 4

Результат на тестовом наборе: 11 / 11

Набор содержит ловушки — все отработаны корректно.

Объект

Габариты, мм

r/R

Кат.

Разбор ловушек

Короб 400×400×300 → C
«обычная» коробка, но 400 > 320 мм
Пуфик → C
круглый, но 489 > 320 — габарит бьёт форму
Ручка → C
9 мм < минимума 10 мм (нижняя граница)
Мешок, Шлем → D
неочевидный круг в сечении — форма, а не имя

Бутылка

305×91×91

1.00

D

Цилиндр

Мешок

435×50×43

202×176×170

0.87

0.89

D

D

Тарелка

210×209×27

1.00

D

Шлем

ЛанчБокс

352×298×282

201×152×62

0.90

0.66

D

B

Короб 300×200×200

301×200×200

0.72

B

Моющее средство

Короб 400×400×300

280×260×179

401×400×300

0.73

0.72

B

C

Пуфик

489×489×264

1.00

C

Ручка

148×13×9

1.00

C

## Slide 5

RGB-D контур: система «видит» товар

Замкнут контур «пиксели → категория». Три depth-камеры (верх + два бока 45°, как в промышленных DWS-тоннелях).

Алгоритмика классификации не меняется — тот же код, что и для STL; меняется только источник геометрии.

облако точек (3 проекции) → эллипс сечения Цилиндра восстановлен: r/R = 0.99 → D

Устойчивость к ориентации товара: 55 / 55 измерений на 5 углах поворота.

3 depth-камеры

→

облако точек

→

сегментация от ленты

→

габариты + круг

→

правило B / C / D

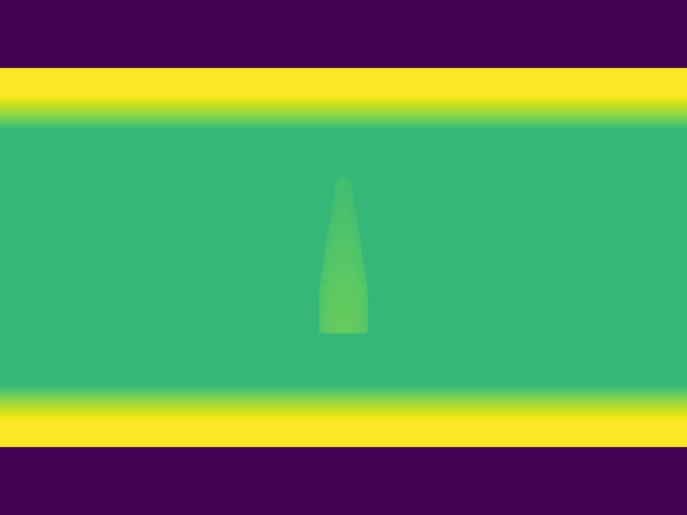
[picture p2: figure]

depth-кадр верхней камеры

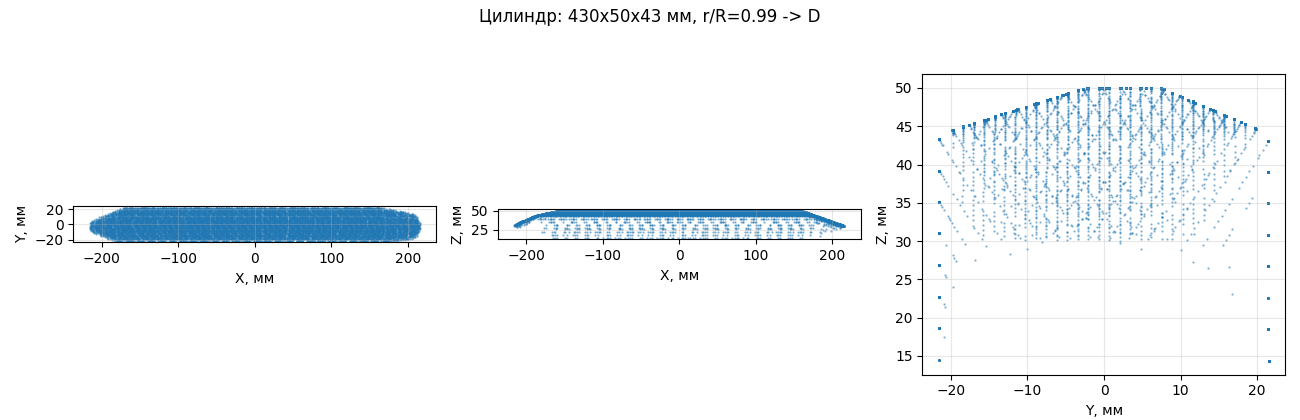
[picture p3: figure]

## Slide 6

Маршрутизация A/B/C/D и исполнительный узел

Схема потока

подача: товар по конвейеру 1 м/с

Накопитель-лоток (tilt-tray): приём → поворот на угол зоны → опрокидывание

Товар неподвижен в момент поворота — исключён перелёт крупного товара через борт. Круглые тела гасит V-образное ложе и торцевой флап.

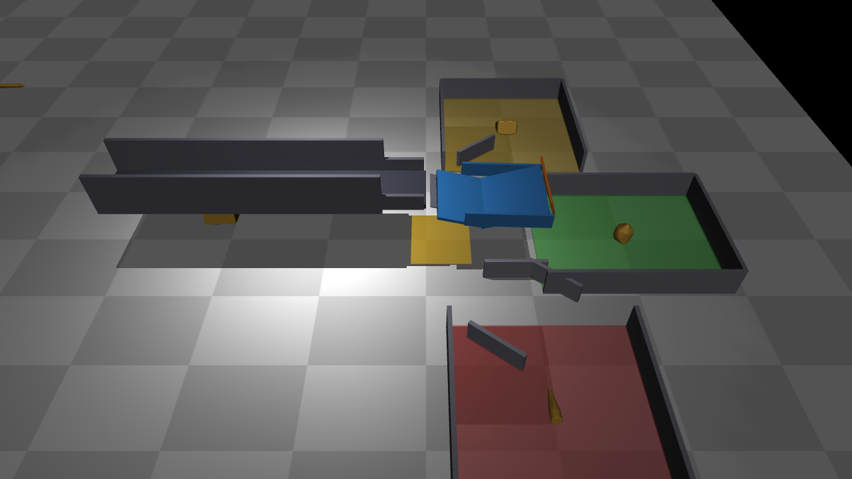
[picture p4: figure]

A

B

основной сортировщик (подходит)

C

негабарит (ролл-кейдж)

D

доупаковка / круг в сечении

Товары B идут прямо; активно изымаются только C и D — это резко снижает требуемый темп узла.

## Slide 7

Инженерная проработка: отказ → решение

Каждый отказ, найденный в симуляции, превращён в конструктивное решение.

Крупный товар перелетает борт при повороте

→

tilt-tray: приём → стоп → поворот → опрокидывание

Круглый товар прострел / качение

→

V-образное ложе + торцевой флап-ловушка

Тонкий товар (9 мм) в щель лента/лоток

→

мостик-переходник + щелевой отсев в C

Высокий круглый скатывается с ленты

→

высокие борта разгонного участка

Плоский товар укатывается мимо кейджа

→

направляющие юбки-каналы к зонам

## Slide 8

Подтверждение работоспособности

Всё проверяется экспертом покомпонентно: код, логи (CSV), визуализации, видео, тесты.

11/11

классификация набора

11/11

RGB-D восприятие

55/55

устойчивость к ориентации

11/11

маршрутизация в симуляции

33/33

стресс-прогон подачи

5.3 с

cycle time (5.8 макс)

35

юнит-тестов проходят

100%

воспроизводимо, ПО из перечня

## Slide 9

Инструменты и почему они

Всё ПО — из перечня допустимого; результаты в нейтральных форматах (CSV, PNG, MP4, STL).

физический цифровой двойник участка: контакты, трение, приводы

OBB-габариты, сечения, вписанная/описанная окружности

RGB-D: облако точек, фильтры, аппроксимация эллипса

детерминированный классификатор и 35 юнит-тестов

MuJoCo

trimesh + shapely

depth-камеры + SciPy

Python + pytest

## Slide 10

Ограничения и развитие

Ограничения

- лента моделируется кинематически
- решение цифровое — физический прототип в планах
- прозрачные/зеркальные товары требуют доработки сенсорики
- поток плотнее cycle time → каскад лотков

Развитие

- перенос RGB-D-контура на физическую камеру (алгоритмика та же)
- физический узел: сервоприводный 3-позиционный лоток
- дискретно-событийная модель потока (AnyLogic)
- каскад/параллельные лотки для масштабирования

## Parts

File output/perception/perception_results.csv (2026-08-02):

name | dim1_mm | dim2_mm | dim3_mm | circle_ratio | category_rgbd | category_reference | match | rgbd_borderline | points
Бутылка | 295.4 | 102.2 | 86.7 | 0.978 | D | D | True | False | 14283
Цилиндр | 430.4 | 50.0 | 43.1 | 0.986 | D | D | True | False | 13280
Короб 300х200х200 | 294.5 | 200.0 | 199.7 | 0.719 | B | B | True | False | 13527
Короб 400х400х300 | 400.0 | 396.2 | 300.0 | 0.711 | C | C | True | False | 13057
ЛанчБокс | 195.6 | 147.8 | 62.3 | 0.629 | B | B | True | False | 14467
Мешок | 175.4 | 170.6 | 170.1 | 0.987 | D | D | True | False | 14060
Моющее средство | 264.5 | 249.0 | 178.0 | 0.721 | B | B | True | True | 14526
Пуфик | 488.9 | 467.5 | 264.7 | 1.0 | C | C | True | False | 14271
Ручка | 146.3 | 12.5 | 9.0 | 0.629 | C | C | True | False | 1500
Шлем | 355.8 | 298.0 | 266.8 | 0.927 | D | D | True | False | 13814
Тарелка | 205.3 | 204.8 | 27.1 | 0.987 | D | D | True | False | 14694

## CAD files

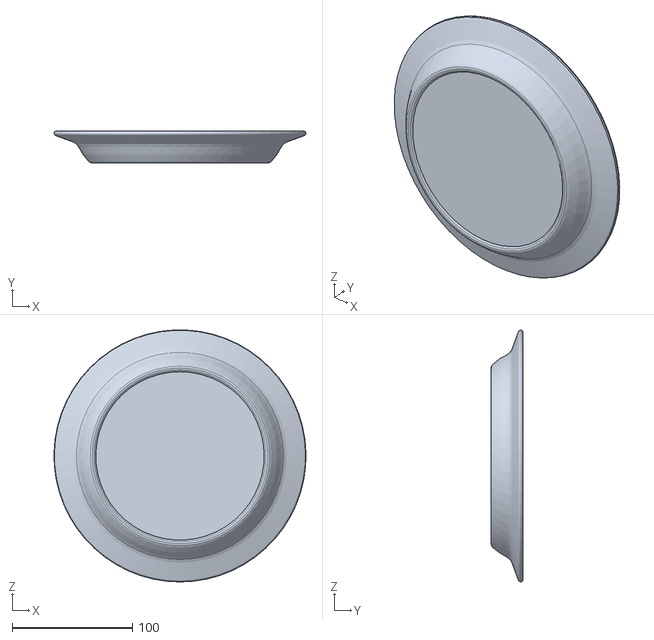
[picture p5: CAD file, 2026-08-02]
data/models/tarelka.stl
209.5 x 26.5 x 209.4

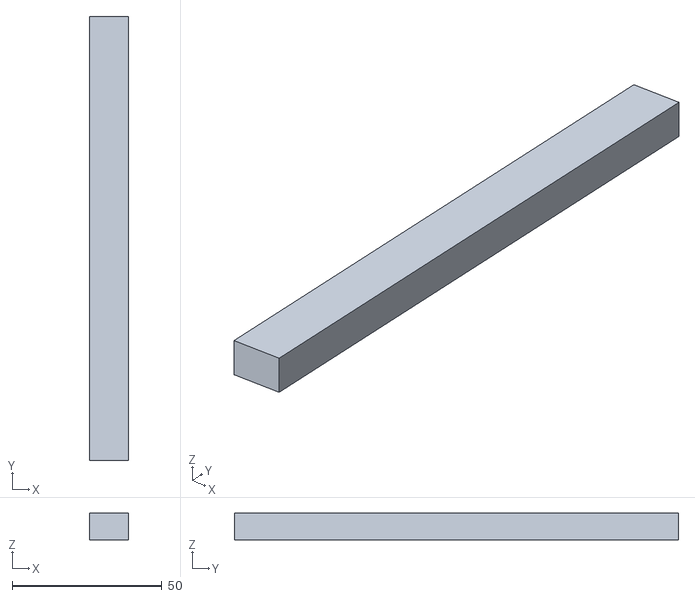
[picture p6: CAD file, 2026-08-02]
data/models_sim/ruchka.stl
13.1 x 148.5 x 9.00

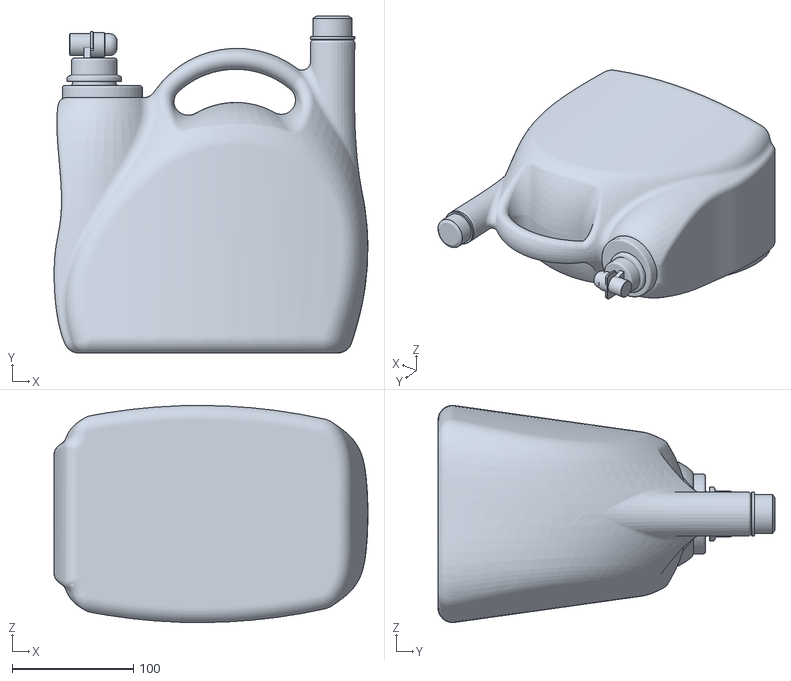
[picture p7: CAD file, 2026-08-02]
data/models/moyushchee_sredstvo.stl
259.0 x 278.2 x 179.2

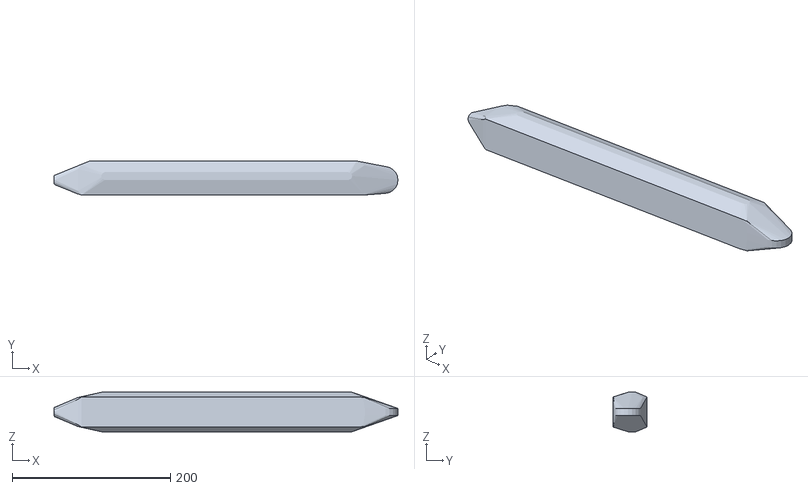
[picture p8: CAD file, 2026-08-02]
data/models_sim/cilindr.stl
435.0 x 43.0 x 50.0

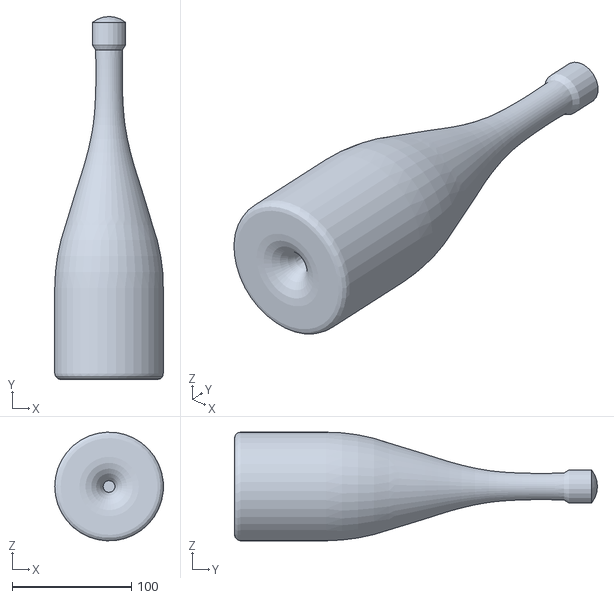
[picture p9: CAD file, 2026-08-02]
data/models/butylka.stl
91.2 x 305.0 x 91.3

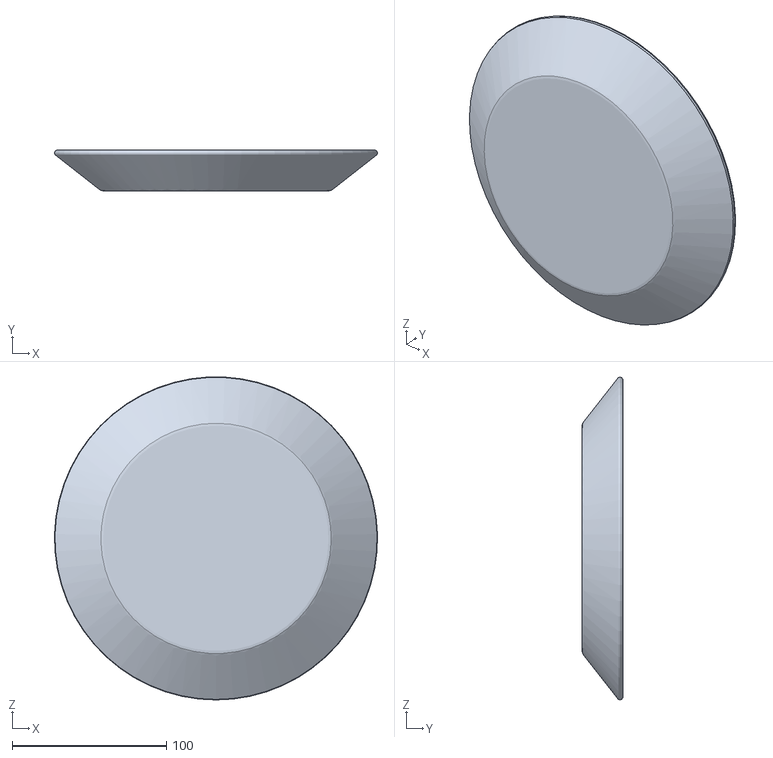
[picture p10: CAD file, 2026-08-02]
data/models_sim/tarelka.stl
209.5 x 26.5 x 209.4

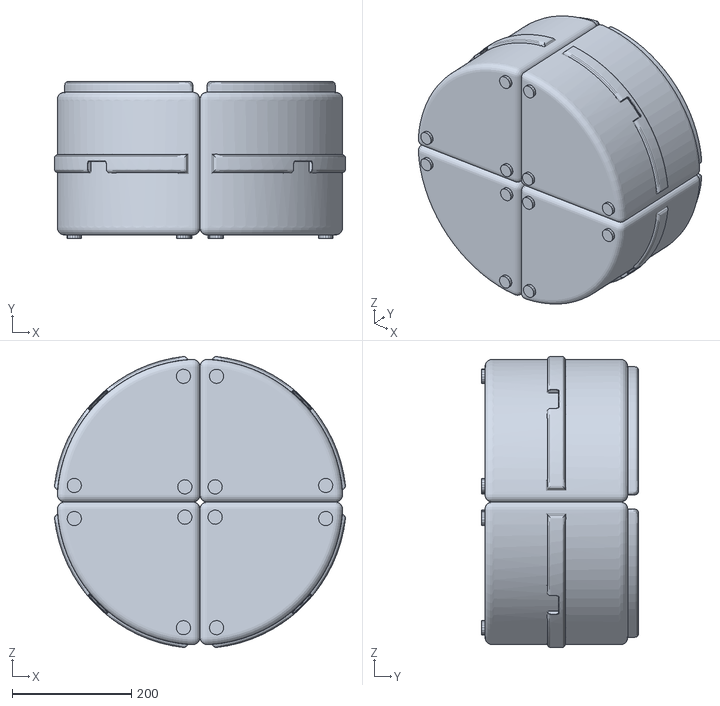
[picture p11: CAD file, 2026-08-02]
data/models/pufik.stl
488.9 x 264.0 x 488.9

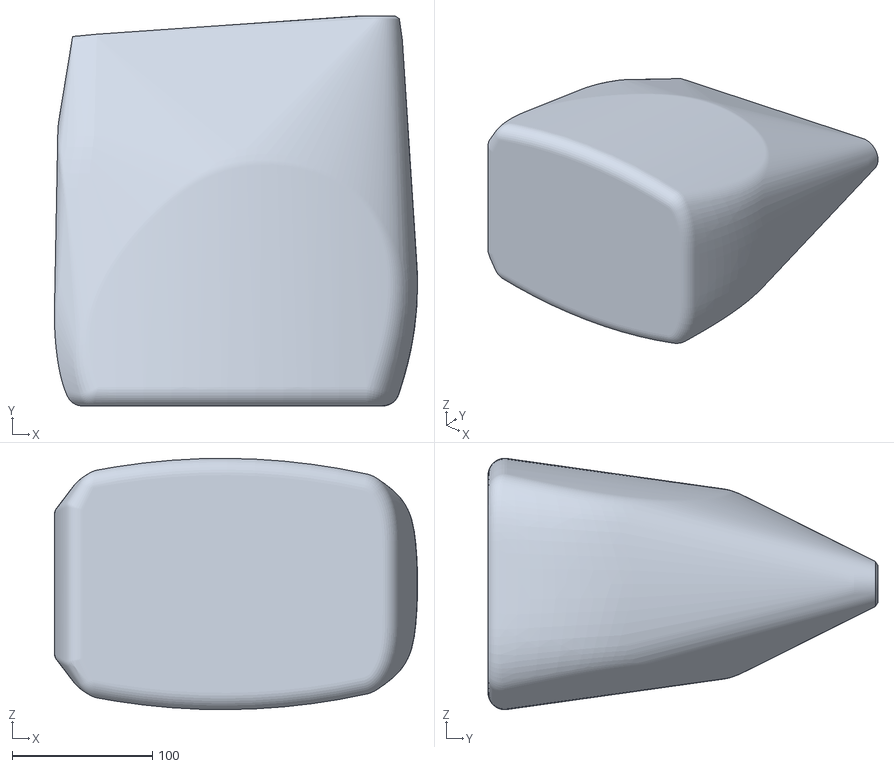
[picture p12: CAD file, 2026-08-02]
data/models_sim/moyushchee_sredstvo.stl
259.0 x 278.2 x 179.2

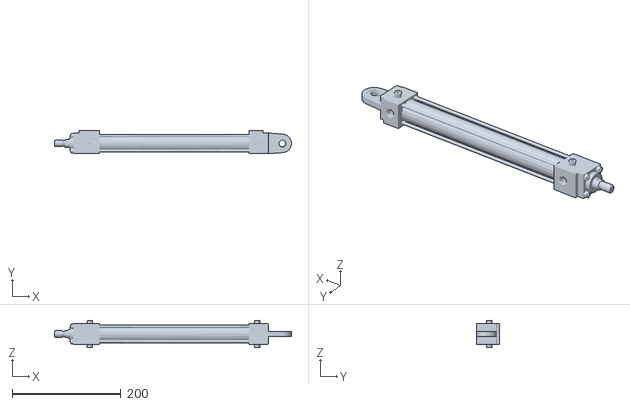
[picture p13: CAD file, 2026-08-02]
data/models/cilindr.stl
435.0 x 43.0 x 50.0

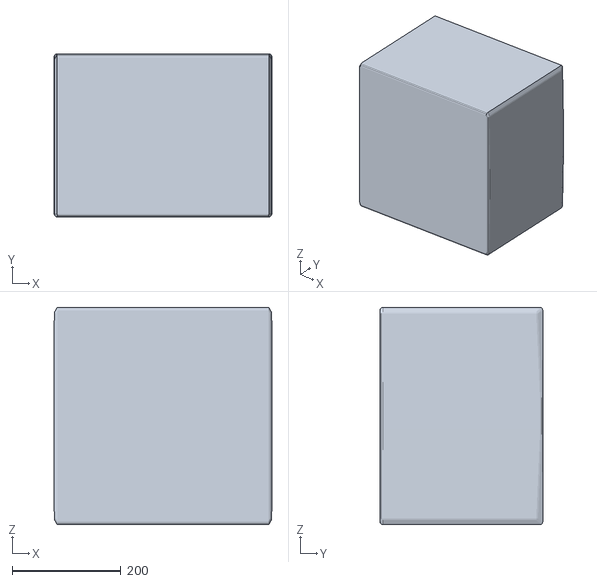
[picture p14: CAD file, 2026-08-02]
data/models_sim/korob_400x400x300.stl
401.0 x 300.5 x 400.0

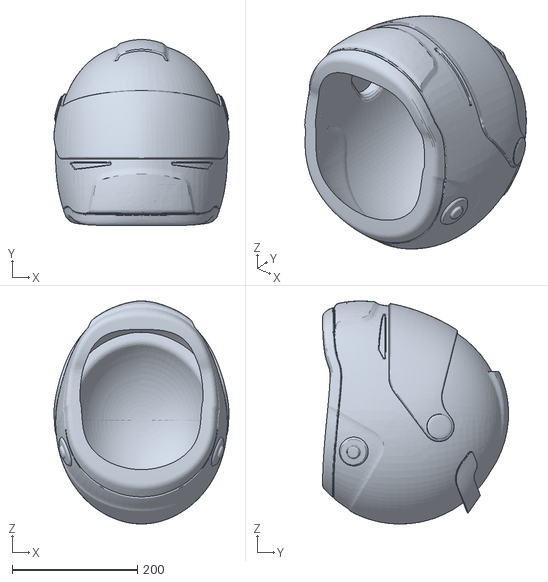
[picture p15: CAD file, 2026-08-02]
data/models/shlem.stl
279.6 x 297.1 x 356.3

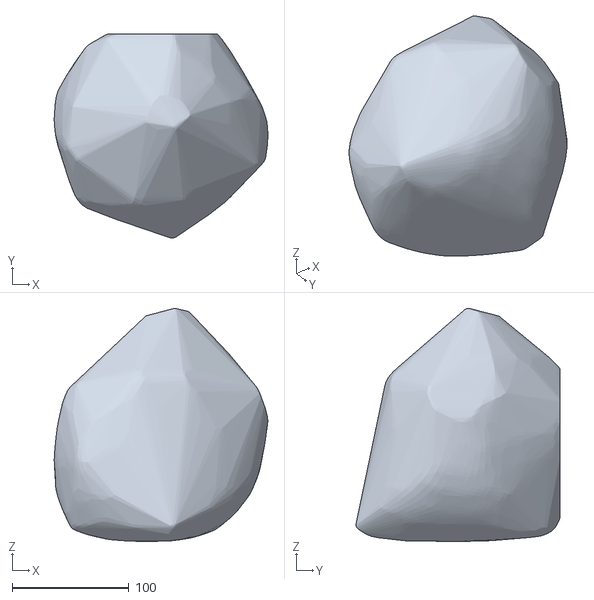
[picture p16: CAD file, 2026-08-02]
data/models_sim/meshok.stl
182.8 x 174.8 x 199.3

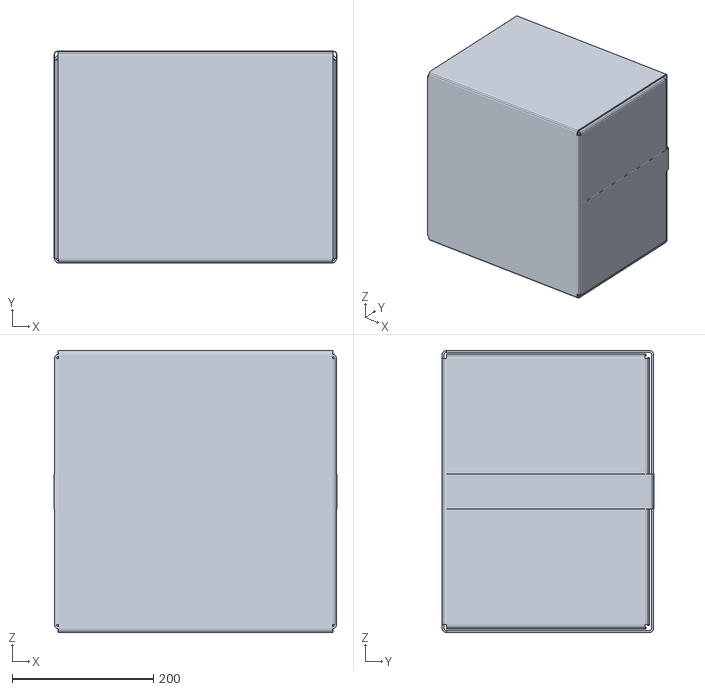
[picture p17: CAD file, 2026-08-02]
data/models/korob_400x400x300.stl
401.0 x 300.5 x 400.0

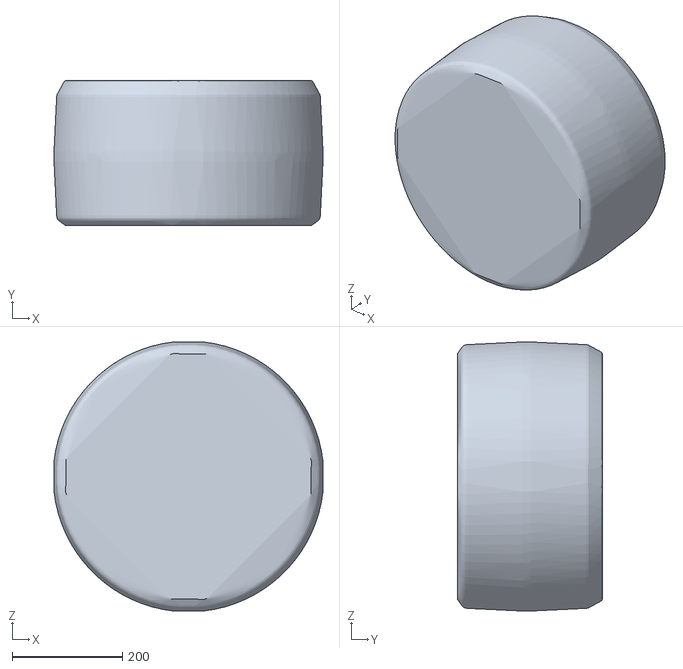
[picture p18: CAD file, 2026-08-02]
data/models_sim/pufik.stl
488.9 x 264.0 x 488.9

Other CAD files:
data/models/ruchka.stl
data/models_sim/korob_300x200x200.stl
data/models/lunchbox.stl
data/models_sim/butylka.stl
data/models/korob_300x200x200.stl
data/models_sim/lunchbox.stl
data/models_sim/shlem.stl

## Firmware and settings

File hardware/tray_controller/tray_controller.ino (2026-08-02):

/*
 * Контроллер 3-позиционного накопителя-лотка (tilt-tray) для ПАК трека 3.
 * Платформа: ESP8266 (NodeMCU). 3 сервопривода: YAW, TILT, FLAP.
 *
 * Реализует ту же логику, что и цифровой двойник sim/conveyor_sim.py:
 *   приём (yaw=0, tilt=приём, флап закрыт) -> поворот на угол зоны ->
 *   опрокидывание (tilt=DUMP, флап открыт) -> возврат.
 *
 * Приём категории двумя способами (связка с частью классификации):
 *   1) Wi-Fi:  HTTP GET  /sort?cat=B|C|D
 *   2) Serial: символ 'B' / 'C' / 'D' (115200)
 *
 * Углы синхронизированы с константами симуляции:
 *   YAW: B=0, C=+55, D=-55 ; TILT: приём=0, опрокидывание=34.
 *
 * ВНИМАНИЕ по питанию: сервоприводы MG996R питать от отдельного БП 5-6 В
 * (>=3 A), землю объединить с ESP8266. От USB сервы не питать.
 */
#include <ESP8266WiFi.h>
#include <ESP8266WebServer.h>
#include <Servo.h>

// ---- Wi-Fi (или режим точки доступа, см. USE_AP) ----
#define USE_AP 1                     // 1 = ESP поднимает свою точку доступа
const char* WIFI_SSID = "robozone";
const char* WIFI_PASS = "robozone802";

// ---- пины сервоприводов ----
const int PIN_YAW  = D1;             // GPIO5
const int PIN_TILT = D2;             // GPIO4
const int PIN_FLAP = D5;             // GPIO14

// ---- углы (в градусах серво 0..180; нейтраль 90 = 0° механики) ----
const int YAW_NEUTRAL = 90;          // калибровать под свою механику
const int YAW_C = YAW_NEUTRAL + 55;  // категория C -> +55
const int YAW_D = YAW_NEUTRAL - 55;  // категория D -> -55
const int TILT_RECEIVE = 80;         // приём (лёгкий контруклон)
const int TILT_DUMP    = 80 + 34;    // опрокидывание +34
const int FLAP_CLOSED  = 70;
const int FLAP_OPEN    = 160;

// ---- тайминги цикла, мс ----
const int T_SETTLE = 500;            // осадка товара в ложе
const int T_ROTATE = 600;            // поворот YAW
const int T_DUMP   = 900;            // сход товара
const int T_RETURN = 700;            // возврат в приём

Servo sYaw, sTilt, sFlap;
ESP8266WebServer server(80);

void moveTo(Servo& s, int a) { s.write(constrain(a, 0, 180)); }

void toReceive() {
  moveTo(sFlap, FLAP_CLOSED);
  moveTo(sTilt, TILT_RECEIVE);
  moveTo(sYaw, YAW_NEUTRAL);
}

// полный цикл сортировки по категории
void sortCycle(char cat) {
  int yaw = YAW_NEUTRAL;
  if (cat == 'C') yaw = YAW_C;
  else if (cat == 'D') yaw = YAW_D;      // 'B' -> нейтраль (прямо)

  delay(T_SETTLE);                        // приём и осадка
  moveTo(sYaw, yaw);   delay(T_ROTATE);   // поворот на зону
  moveTo(sTilt, TILT_DUMP);
  moveTo(sFlap, FLAP_OPEN);  delay(T_DUMP);  // опрокидывание + флап
  toReceive();         delay(T_RETURN);   // возврат
}

void handleSort() {
  String c = server.arg("cat"); c.toUpperCase();
  if (c == "B" || c == "C" || c == "D") {
    Serial.printf("HTTP sort -> %s\n", c.c_str());
    sortCycle(c[0]);
    server.send(200, "text/plain", "ok " + c);
  } else {
    server.send(400, "text/plain", "cat must be B|C|D");
  }
}

void setup() {
  Serial.begin(115200);
  sYaw.attach(PIN_YAW); sTilt.attach(PIN_TILT); sFlap.attach(PIN_FLAP);
  toReceive();

#if USE_AP
  WiFi.softAP(WIFI_SSID, WIFI_PASS);
  Serial.print("AP IP: "); Serial.println(WiFi.softAPIP());
#else
  WiFi.begin(WIFI_SSID, WIFI_PASS);
  Serial.print("connecting");
  while (WiFi.status() != WL_CONNECTED) { delay(300); Serial.print('.'); }
  Serial.print("\nSTA IP: "); Serial.println(WiFi.localIP());
#endif

  server.on("/sort", handleSort);
  server.on("/", []() { server.send(200, "text/plain",
            "tray_controller ready. GET /sort?cat=B|C|D"); });
  server.begin();
  Serial.println("HTTP server up. Serial: send B/C/D.");
}

void loop() {
  server.handleClient();
  if (Serial.available()) {                 // Serial-фолбэк
    char c = toupper(Serial.read());
    if (c == 'B' || c == 'C' || c == 'D') {
      Serial.printf("Serial sort -> %c\n", c);
      sortCycle(c);
    }
  }
}

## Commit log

2026-08-02 Задача 3: интеллектуальная роботизированная система сортировки товаров
    ПАК: детерминированная классификация B/C/D, RGB-D восприятие,
    цифровой двойник (MuJoCo, tilt-tray), проект физического узла, 35 тестов.
    [butylka.stl, cilindr.stl, classification.csv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]
2026-08-02 Добавлена модель пропускной способности (непрерывный поток, SimPy) + физузел, презентация
    [throughput.csv]
2026-08-02 Добавлена видеодемонстрация полного цикла (sim_demo.mp4)
